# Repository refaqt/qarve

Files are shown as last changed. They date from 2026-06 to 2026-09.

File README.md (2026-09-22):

# Qarve

Open-source modular CNC milling machine — text-first, Git-friendly, [DOQS](https://github.com/refaqt/doqs) documentation system.

The repository root is the **top-level DOQS module**. Sub-assemblies will live under `modules/` when added; none exist yet.

## Quick start

1. Clone with submodules: `git clone --recurse-submodules https://github.com/refaqt/qarve.git`
2. From the repo root, agents run `bash setup-tooling.sh` so `doqs/` and `.agents/` track latest `main`. Humans on Windows may double-click `setup-tooling.bat`. Do not run those helpers from `doqs/templates/setup-tooling/`.
3. Install https://git-lfs.com/ and run `git lfs install` before pulling CAD binaries.
4. Read `docs/onboarding.md` for tooling, validation, and agent workflow.
5. Open `architecture/machine.sysml` for system requirements, or double-click `syson.bat` for the SysON control panel (Docker Desktop once; see `doqs/docs/syson.md`).

## Validation

From the repository root:

```powershell
python doqs/doqs.py check
```

This is the same command the automatic checks run on every pull request. It checks the part manifests, the licence files, the names, the links, the build records, the variants, and the FreeCAD models. It also checks that every generated file is up to date.

To write the generated files again, run:

```powershell
python doqs/doqs.py generate
```

After adding a first-level content directory, also run `python doqs/scripts/apply_licenses.py` to give it a licence file.

## Layout

| Path | Role |
| --- | --- |
| `LICENSE` | Overview mapping directories to licences |
| `LICENSES/` | Full CERN-OHL-S, GPL-3.0, and CC BY-SA texts |
| `TRADEMARKS.md` | Reserved organisation and project marks |
| `architecture/` | Top-level SysML (requirements, interfaces) |
| `cad/` | Machine assembly FreeCAD + exports |
| `modules/` | Reserved for future sub-assemblies (empty today) |
| `builds/` | Physical machine lockfiles |
| `graph/` | Generated reverse-usage graph |
| `doqs/` | Git submodule — shared tools, templates, schemas |
| `.agents/` | Git submodule — shared agent rules and skills |
| `.agents-local/`  | Qarve-only agent rules and skills |
| `firmware/` | Motion controller and related software |
| `docs/` | Narrative: log, mistakes, decisions |

## Agents

Cursor, Claude Code, and cloud agents: start at [`AGENTS.md`](AGENTS.md). Shared kit is in
[`.agents/`](.agents/); repo-specific rules and skills in [`.agents-local/`](.agents-local/).

## Licence

This repository uses different licences for different kinds of content:

- **Hardware** (`cad/`, `architecture/`, `manufacturing/`, `bom/`, `builds/`, `modules/`) —
  [CERN-OHL-S v2.0](LICENSES/CERN-OHL-S-2.0.txt)
- **Firmware & software** (`firmware/`, `software/`, `simulation/`) —
  [GPL-3.0](LICENSES/GPL-3.0.txt)
- **Media & documentation** (`docs/`, `measurement/`) —
  [CC BY-SA 4.0](LICENSES/CC-BY-SA-4.0.txt)

The Refaqt BV, BE 0804.145.539 name and logo, and the Qarve CNC Milling Machine name and logo, are
trademarks and are not covered by the above — see [TRADEMARKS.md](TRADEMARKS.md).

See [LICENSE](LICENSE) for the full overview and directory mapping.

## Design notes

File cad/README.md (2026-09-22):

# Top-level CAD

- **FreeCAD:** v1.1+ with built-in Assembly workbench.
- **Relative paths:** `Edit → Preferences → General → Document → Use relative paths when saving external links`.

## Paths

| Path | Purpose |
|---|---|
| `assemblies/machine.FCStd` | Top assembly (future; may link into `modules/*/cad/` when sub-assemblies exist) |
| `assemblies/spindle-assembly/` | Spindle stack assembly |
| `assemblies/spindle-clamp/` | Spindle clamp sub-assembly |
| `parts/spindle/` | Purchased spindle model (JGY-80) and reference images |
| `parts/spindle-clamp-base/` | Clamp base part (recess for spindle clearance) |
| `parts/spindle-clamp-jaw/` | Clamp jaw part |
| `parts/spindle-clamp-flex/` | Clamp flex part |
| `exports/` | `.step`, `.stl` committed after significant changes |

## Top-down design (spindle clamp)

Master sketches for the clamp live in `spindle-clamp.FCStd` inside a `Master sketches` group and a dedicated `Body_master` (`PartDesign::Body`). Sketches use **that Body's origin planes**, not the `Assembly` object's origin planes. Child parts (`spindle-clamp-base`, `spindle-clamp-jaw`) consume geometry via `SubShapeBinder` pointing at sketches inside `Body_master`.

This avoids a circular document dependency (assembly → part → assembly) that blocks Assembly **Insert**. See `doqs/docs/decisions/2026-06-24_freecad-master-sketches-body.md` and `doqs/docs/architecture.md` (Top-down design and master sketches).

Binary `.FCStd` / `.stl` use Git LFS (see root `.gitattributes`).

## After you save a model

Every `.FCStd` has a `.fingerprint.json` beside it. It lists the size, the
position and the volume of each object, so a change to the geometry can be read
as text in a pull request. The checks fail when a model and its measurement
disagree.

Run this from the repository root after saving, and commit the model and the
measurement together:

```powershell
python cad/fingerprint_models.py
```

The script opens each model, measures it and closes it. It never saves a
`.FCStd`: geometry changes stay manual, in the FreeCAD window. The run ends by
naming any model whose geometry moves when FreeCAD refreshes it, which means the
saved file no longer matches its own sketches and joints.

Why this repository measures models instead of rebuilding them:
[`docs/decisions/2026-09-22_fingerprints-for-hand-drawn-models.md`](../docs/decisions/2026-09-22_fingerprints-for-hand-drawn-models.md).

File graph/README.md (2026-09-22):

# Usage graph

`usage-graph.json` is **generated** by `doqs/scripts/resolve_graph.py` and committed as a snapshot of which parents and builds reference each module.

```powershell
python doqs/doqs.py generate
```

To check that the committed file is still current, without writing it:

```powershell
python doqs/scripts/resolve_graph.py --check
```

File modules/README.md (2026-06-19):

# Modules

This directory is reserved for **sub-assemblies** — each a full DOQS module with the same layout as the repository root (`bom/`, `cad/`, `architecture/`, `docs/`, `manufacturing/`, `modules/`).

**Current state:** Qarve is a single top-level module. No sub-assemblies exist yet.

When you add the first sub-module:

1. Create `modules/<name>/` with the standard module layout.
2. Register it in the root `okh.toml` via `[[hasComponent]]`.
3. Import its SysML from `architecture/machine.sysml`.
4. Pin it in `builds/<id>/build.toml`.

Later, a sub-module can be extracted to its own repository and linked back as a Git submodule at the same path — see [doqs/docs/architecture.md](../doqs/docs/architecture.md).

Interface version bridges live under `modules/adapters/` by convention.

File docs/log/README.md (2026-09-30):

# Activity log

Chronological record of work on Qarve (engineering and design). Entries follow
`YYYY-MM-DD_topic.md`, newest listed last. Every entry must include **Role(s)**.

To add an entry, see [`.agents/skills/log/SKILL.md`](../../.agents/skills/log/SKILL.md).

| Date | Topic | Role(s) | Images |
| ---- | ----- | --- | -----: |
| 2026-06-04 | [Repository bootstrap](2026-06-04_repository-bootstrap.md) | engineering |  |
| 2026-06-23 | [Spindle clamp design](2026-06-23_spindle-clamp-design.md) | engineering |  |
| 2026-06-26 | [Guide-rail adjustment simulation](2026-06-26_guide-rail-adjustment-simulation.md) | engineering |  |
| 2026-06-26 | [Z-axis CAD bootstrap](2026-06-26_z-axis-cad-bootstrap.md) | engineering |  |
| 2026-08-11 | [FEM CalculiX assembly material/mesh workflow](2026-08-11_fem-calculix-assembly-workflow.md) | engineering, simulation |  |
| 2026-08-15 | [X-axis Params and AssemblyLink pattern](2026-08-15_x-axis-params-assemblylink-pattern.md) | engineering, cad |  |
| 2026-08-28 | [Taiwanese ATC spindle supplier research](2026-08-28_taiwanese-atc-spindle-suppliers.md) | engineering |  |
| 2026-08-28 | [Agent kit and log restructure](2026-08-28_agent-kit-and-log-restructure.md) | engineering |  |
| 2026-08-31 | [Split-licence layout](2026-08-31_split-licence-layout.md) | engineering |  |
| 2026-09-01 | [Always-latest tooling submodules](2026-09-01_always-latest-tooling-submodules.md) | engineering |  |
| 2026-09-01 | [SysON session adapter](2026-09-01_syson-session-adapter.md) | engineering, software |  |
| 2026-09-22 | [Linear axis reworked around the steel strip seal](2026-09-22_linear-axis-seal-roller-clearance.md) | engineering, cad |  |
| 2026-09-22 | [The repository passes its own checks again](2026-09-22_repository-passes-its-own-checks.md) | engineering, software |  |
| 2026-09-23 | [Linear stage base redrawn as one aluminium block](2026-09-23_linear-stage-monoblock-base.md) | engineering, cad | 1 |
| 2026-09-25 | [Strip seal is thicker and bends on a larger radius](2026-09-25_strip-seal-thicker-with-larger-bend-radius.md) | engineering, cad |  |
| 2026-09-28 | [Controller comparison: grblHAL and ncSender against LinuxCNC and EtherCAT](2026-09-28_controller-comparison-grblhal-vs-linuxcnc-ethercat.md) | engineering, firmware, software |  |
| 2026-09-30 | [Idea: a printed clamp with crossed countersunk screws](2026-09-30_crossed-countersunk-screw-clamp-idea.md) | engineering, hardware | 1 |
| 2026-09-30 | [Y-axis mounted on the frame with eccentric countersunk screws](2026-09-30_y-axis-to-frame-connection.md) | engineering, hardware | 2 |

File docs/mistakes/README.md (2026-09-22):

# Mistakes log

One file per incident: `YYYY-MM-DD_short-topic.md`. Use template `doqs/templates/mistake-entry.md`.

Agents: read all recent entries (or this README’s prevention summary) at task start; append a new file after each mistake — do not use a single `mistakes.md` at repo root.

## Prevention rules (bootstrap)

- Do not edit `.FCStd` files in the agent — use FreeCAD and param CSV workflow.
- Do not hand-edit generated `bom/bom.csv` (root) or `cad/params.csv`.
- Run `python doqs/doqs.py check` before claiming manifests, builds or models are valid.
- After `apply_licenses.py`, confirm `.agents/` and `doqs/` are unmodified (tooling submodules, not machine modules).
- A check that reads a `.FCStd` must be proved on a fresh checkout. Git LFS files are stubs there unless the checkout fetches them.

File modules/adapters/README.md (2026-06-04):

# Adapter modules

Modules that translate between **interface versions** (e.g. spindle mount v1 → v2). Same layout as any other module; declare both `[[provides-interface]]` and `[[consumes-interface]]` in `okh.toml`.

Browse this folder for supported upgrade paths on deployed machines.

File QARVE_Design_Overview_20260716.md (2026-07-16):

# QARVE — Compact 5-Axis CNC Milling Machine: Design Overview

*Reference summary derived from `QARVE__Architecture_Calculations_BOM__20260716.xlsx` (preliminary design, updated 2026-07-16). This document is a navigation aid for the project: it summarizes the concept, kinematics, key calculated numbers, the major components and their suppliers, and known data-quality caveats so that questions can be answered without re-reading the full workbook. Changes versus the prior 2026-06-18 revision are noted inline (the X-axis linear-motor peak-force shortfall is now resolved; the BOM was reorganized and the machine total is lower).*

---

## 1. What QARVE is

QARVE is a **compact, table-tilting 5-axis CNC milling machine** intended to sit on roughly **half a EUR pallet**. The three linear axes (X, Y, Z) position the spindle/tool, and two rotary axes (A, C) orient the workpiece on a **trunnion (cradle) rotary table**. It is built largely from **aluminium extrusion** and uses **direct-drive linear motors** on the linear axes and **frameless torque motors** on the rotary axes.

The design is captured in a single workbook that combines a **parametric system model** (cutting physics → axis loads → motor/component sizing), a **bill of materials with architecture tree**, and a **supplier/specification comparison** that checks each chosen component against the model's requirements.

### Headline figures

| Item | Value |
| --- | --- |
| Axes | 5 — X, Y, Z (linear) + A, C (rotary) |
| Linear travels | X = 310 mm · Y ≈ 356 mm total (≈256 mm machining + 100 mm tool change) · Z = 222 mm |
| Max workpiece | Ø230 mm × 210 mm tall; ≈163 × 163 mm if square; **15 kg** max |
| Target machine footprint | ≤ 600 mm (X, ½ EUR-pallet length) × 800 mm (Y, EUR-pallet width) |
| Spindle | Jianken JGY-80/3.2R24-encoder, PMSM, **ISO20**, up to ~30,000 rpm |
| Materials targeted | Aluminium 6061, Stainless 304L, Titanium Ti-425 (roughing + finishing each) |
| Finishing stiffness target | ≤ **2 µm** deflection at ≈95 N finishing force |
| Indicative total BOM cost  | ≈ **€21,029** (Parts/Architecture roll-up, EUR). Note: this **excludes the Accessories block (A21, ≈€2,820)**, which is defined but currently detached from the machine tree — see §7–8. With accessories re-attached the effective total is ≈**€23,850**. See §8 for the one USD-quoted line and how it's handled. |

---

## 2. Kinematics & axis architecture

QARVE is a **moving-gantry / tilting-table** configuration:

- **Gantry** spans the work zone on two **80 mm support columns**; the gantry beam is ~530 mm long.
- **X axis** — the spindle carriage traverses *along* the gantry beam (310 mm travel).
- **Y axis** — motion along the machine frame (≈356 mm total travel; frame length in Y ≈760 mm).
- **Z axis** — vertical spindle motion (222 mm), counterbalanced by gas springs.
- **A axis** — the **trunnion/cradle tilt** that swings the rotary table; carries the largest rotary load (heavy, eccentric — see §4).
- **C axis** — the **rotary worktable** (circular T-slot table) seated in the cradle.

> **Naming note (updated):** In the 2026-07-16 workbook the *Groups* sheet now labels the rotary-table group **G05 as "Axis C"**, consistent with Parts/Architecture. The earlier "Axis B (G05)" discrepancy is resolved. A = tilt, C = table rotation.

All three linear axes share a common motion architecture: HIWIN profile rail + blocks, an iron-core linear motor (Saho **WJM50-3** — new selection this revision, see §4), a linear encoder for feedback, bellows covers, end stops, limit sensors, and shock dampers. Both rotary axes share: a frameless torque motor, roller bearings, bearing/motor housings, a rotor disk, and a rotary encoder.

---

## 3. Cutting capability & the system model

The "System model" sheet is the parametric heart of the workbook. For each **material × operation** it sets cutting parameters and tool geometry, then computes forces, torque, power and required dynamics. Cases modelled:

| Case | Tool (Hans Treiber) | Ø | Flutes | vc (m/min) | Spindle (rpm) | Cutting power (W) | Spindle torque (Nm) | Resultant cut force (N) |
| --- | --- | ----- | --- | --- | --- | --- | --- | --- |
| Aluminium 6061 — roughing | RG28-88RZ (N 1.2) | 10 mm | 3 | 620 | ~19,700 | ~1,491 | 0.72 | ~192 |
| Aluminium 6061 — finishing  | HP-AL3L-DLC (N 1.2) | 6 mm  | 3 | 450 | ~23,900 | ~236 | 0.094 | ~42 |
| Stainless 304L — roughing | RG26-48TZ (M 2.1) | 10 mm | 4 | 130 | ~4,140 | ~325 | 0.75 | ~201 |
| Stainless 304L — finishing  | RG26-44T (M 2.1) | 6 mm  | 4 | 120 | ~6,370 | ~115 | 0.17 | ~77 |
| Titanium Ti-425 — roughing  | RG26-48TZ (S 1.2) | 10 mm | 4 | 100 | ~3,180 | ~239 | 0.72 | ~192 |
| Titanium Ti-425 — finishing | RG26-48TZ (S 1.2) | 6 mm  | 4 | 100 | ~5,310 | ~118 | 0.21 | ~95 |

Material cutting coefficients used: aluminium Kc1.1 = 800 MPa (mc 0.25); stainless Kc1.1 = 2150 MPa (mc 0.20); titanium Kc1.1 = 2110 MPa (mc 0.22). Target metal-removal rate (MRR) for aluminium roughing is 50 cm³/min.

The model uses a chip-thinning / energy-weighted Kc approach (radial chip-thinning factor, average Kc at max chip thickness) to derive **tangential, feed, transverse and axial forces**, and from those the **spindle torque/power** and the **per-axis acceleration forces**. The governing worst case for sizing the linear axes and rotary process force is **≈201 N resultant cutting force** (stainless/titanium roughing); the **finishing** worst case (~95 N, titanium) drives the **2 µm stiffness** requirement.

> Two trailing sheets — *"Oblique cutting constants (not used)"* and *"Cutting force model (replaced w…)"* — are **deprecated**. The oblique-cutting table holds representative orthogonal constants that the notes say were *not* used; the old cutting-force model sheet is full of `#REF!` errors and has been superseded by the per-case calculations in "System model." Treat both as historical, not authoritative.

---

## 4. Motor & drive sizing (calculated requirements → selected hardware)

### Linear axes (X / Y / Z)

- Peak per-axis acceleration ≈ 19.1 m/s² (feed) / 13.9 m/s² (rapids); rapid speed 5,000 mm/min.
- Continuous motor force required ≈ **201 N**; peak force required ≈ **418 N (Z) / 479 N (Y) / 565 N (X)** — X remains the worst case at **564.8 N**.
- **Selected (changed this revision):** Saho **WJM50-3** forcer (200 mm, force constant 52.2 N/A, 240 N continuous, **750 N peak**, 4.6 A cont., 600 V, 139.7 W thermal @100 °C) on Saho **DJM050** stators (DJM050-L80 + DJM050-L200). Forcer unit cost ≈€101 (vs ≈€172 for the old WKM030-2), which is the main reason the X/Y/Z assembly costs dropped (§7).
- ✅ **Open issue RESOLVED:** with the WJM50-3's **750 N peak** rating, the X-axis peak-force requirement (564.8 N) now passes with margin. **All linear-motor spec lines are TRUE** in this revision. (The previously selected Saho WKM030-2 — 532 N peak, 106 W thermal, 4.5 A — failed on peak force, continuous current, force constant, resistance and thermal power, and is now the rejected alternative.)
- ⚠ Note the trade: WJM50-3 continuous thermal dissipation is **139.7 W** per forcer (vs 106 W for the old part), raising per-axis and total machine heat (see below) — worth watching for natural-cooling margin, though continuous force (201 N) sits well under the 240 N continuous rating.

### Rotary axes (A / C)

- A-axis (trunnion) continuous torque required ≈ **27.7 Nm** (dominated by the eccentric centre-of-gravity of the cradle, ~31.4 Nm static term, plus eccentric workpiece up to ~4.6 Nm and process torque).
- C-axis (table) continuous torque required ≈ **23.1 Nm**.
- **Selected:** **Mosrac U16060** frameless torque motor (torque constant 1.6 Nm/A, 32 Nm continuous, 45 A peak, 48 V DC, 0.96 Nm cogging, 0.24 Ω) — unchanged; all spec lines pass. Unit cost rolled in ≈€520 (USD-quoted supplier line, see §8). Resistive heaters appear on the A-axis (thermal conditioning).
- Alternatives evaluated but rejected: Mosrac U20060, and Seninter/3Phis DDM140050-PM and DDM140070-PM (the DDM140050-PM fails several lines — torque constant 9.9 vs 1.6 Nm/A, continuous/instant current, and 380 V vs 48 V DC-voltage mismatch).

### Drives & power

- **Servo drives:** Nanotec **N5-2-1** (one per motion axis; 6 listed in the BOM, ≈€363 each rolled).
- **Spindle drive:** **Cumark ES850S-02-4K0G-encoder** VFD (≈€327), matched to the encoder spindle for closed-loop / constant-torque-at-low-speed operation.
- **Power:** 48 V / 500 W supply + 12 V supply; per-motor fuses, overcurrent protection, differential breaker; a **mini-PC** acts as the controller.
- Estimated **max continuous machine heat ≈ 171 W** (up from ≈159 W, driven by the higher-dissipation linear forcers); A-axis still dominates at ~72 W (C ~50 W, X ~49 W, Y ~49 W, Z ~27 W).

---

## 5. Spindle

- **Selected (model designation updated):** Jianken **JGY-80/3.2R24-encoder** — a permanent-magnet synchronous-motor spindle, 80 mm body, **ISO20** tool interface, ~10 kg (12 kg with mount), 8.6 A. This revision selects the **encoder-equipped** variant (closed-loop, constant torque at low speed), rolled in at **≈€1,378** (the plain JGY-80/3.2R24 without encoder was ≈€1,178). The earlier "JGY-80/3.7R24" designation is now a listed alternative with no confirmed price.
- Requirement checks all pass: needs ≥3,200 W rated (model needs ~1,657 W), ≥1.32 Nm (needs 0.75 Nm), reach the ~23,900 rpm finishing speed (spindle goes to ~30,000 rpm), runout ≤5 µm (spindle 3 µm), ISO20 match, 8.6 A.
- Paired VFD: **Cumark ES850S-02-4K0G-encoder** (≈€327).
- Spindle rigidity at the tool tip is taken as ~47 N/µm.
- **Alternatives evaluated:** HSD ES330 (€3,500), Teknomotor ATC71-A-ISO30 (€3,500), Hiteco QE-1F (€4,045) / QD-1F (€3,495), and the cheaper Jianken JGL-80/2.2R30. The encoder JGY unit was chosen as the best cost/performance fit.

---

## 6. Structure, precision & enclosure

- **Frame & base:** aluminium extrusion — 80×80 profiles (large), 40 mm (small). The base uses ~17× 80×80×1000 extrusions plus support feet, chip bin, doors and covers; the frame uses 80×80×600 extrusions plus laser-cut side/front/back/inner plates and rubber feet.
- **Gantry beam:** aluminium, area moment of inertia 4,202,400 mm⁴ (from the Misumi catalog), E = 69,000 MPa → ~**374 N/µm** stiffness for a centre point load (clamped-clamped, rails not included).
- **Precision target:** ≤ **2 µm** total machine deflection during finishing at the ~95 N finishing force; tool-tip spindle rigidity ~47 N/µm.
- **Enclosure/housing:** 15 mm enclosure walls with 5 mm clearance to the machine; housing side panels, extrusion sub-frame and a door.

---

## 7. Bill of materials & sub-systems

The **Parts** sheet defines the assemblies (`A01…A21`) and parts (`P01…P82`); **Architecture** is the parent→child tree that rolls quantities and costs up to the top-level assembly **QARVE (A01)**.

**BOM reorganization this revision (read before quoting the total):** the top-level tree was restructured. The **tool setter (P75)**, **wireless touch probe (P76)** and a new **Lighting (P82)** item were promoted to *direct* children of QARVE (A01), and **Control panel (A12)** is now a direct A01 child. Crucially, the **Accessories assembly (A21)** — 12× ISO20 tool holders (€1,800), a **vise set** (€300) and a 12-piece **tool set** (€720), €2,820 total — is **defined but no longer attached to A01**, so it is **not rolled into the machine total**. This is most likely an unintended orphan from the restructure (the probe/setter were moved out of A21 to A01 but the remaining accessories were left detached); flag it before treating €21,029 as the all-in cost.

Direct children of QARVE (A01) and their rolled costs (EUR, as recorded in the workbook):

| Assembly / part | Rolled cost (€) | Notes |
| --- | --- | --- |
| X-axis (A02) | 1,920 | linear motor (WJM50-3) + HIWIN guides + encoder + extrusion |
| Y-axis (A03) | 1,654 | two forcers (longer travel) |
| Z-axis (A04) | 1,020 | + gas-spring counterbalance |
| A-axis (A05) | 1,990 | trunnion: torque motor, bearings, cradle plates, heaters |
| C-axis (A06) | 1,960 | rotary T-slot table, torque motor, bearings |
| Spindle assembly (A07) | 1,778 | spindle + bracket + Cumark VFD |
| Frame (A08) | 1,980 | extrusion + plates |
| Base (A09) | 2,260 | extrusion, doors, chip bin |
| Housing (A10) | 380 | panels + door |
| Electronic system (A11) | 3,477 | drives, PSUs, protection, mini-PC, cabinet |
| Control panel (A12) | 700 | now a direct A01 child |
| Tool coolant system (A13) | 350 | **MQL** (minimum-quantity lubrication) |
| Pneumatic system (A14) | 600 | compressor, filter, valve, components |
| Tool cabinet (A15) | 760 | manual tool storage (tool array holders) |
| Tool setter (P75) | 50 | promoted to direct A01 child |
| Wireless touch probe (P76) | 150 | promoted to direct A01 child |
| Lighting (P82) | 0 | new line, placeholder cost |
| **QARVE total (A01)** | **≈ 21,029** | top-level roll-up (**excludes** detached Accessories A21) |
| *Accessories (A21) — detached* | *2,820* | *vises, tool set + 12 holders; not in the A01 total this revision* |
| *Effective total with A21 re-attached* | *≈ 23,849* | *if the orphan is intended to be included* |

**Accessories & metrology:** a **wireless touch probe** and a **tool setter** (now direct machine sub-assemblies); a **vise set** (low-profile vise + dedicated 5-axis vise); a **tool set** of 12 tools on 12 ISO20 tool holders stored in the tool cabinet (no automatic tool changer — tool change uses the 100 mm Y allowance and the cabinet). The vise set, tool set and tool holders sit under the currently-detached A21 assembly.

### Key suppliers (selected)

- **Sorotec** (DE) — tool holder (ISEL SK20), HIWIN linear guide rails (HGR20) and blocks (HGH20CA).
- **Saho** — linear motor forcers and stators (**WJM50-3** forcer + **DJM050-L80 / DJM050-L200** stators; changed from WKM030-2 / DKM030 this revision).
- **Sino** — linear encoders (KA-500 series).
- **Nanotec** — N5-2-1 servo drives.
- **Mosrac** — U16060 frameless torque motors.
- **Jianken** — **JGY-80/3.2R24-encoder** spindle, with a **Cumark ES850S** VFD.
- **Hans Treiber / fraeser-shop** — solid-carbide end mills (the tools in §3).

---

## 8. Data-quality caveats (read before quoting numbers)

1. **Cost reconciliation error (persists).** The *Groups* sheet still flags **"ERROR: double-counted — an assembly…"**. The sum of the per-group costs (now ≈**13,426**, down from ≈14,452) does **not** equal the top-level QARVE cost (≈21,029); the difference is partly un-grouped systems (frame, base, housing, electronics, coolant, pneumatics, tool cabinet, control panel, probe/setter) and partly a flagged double-count (servo drives are children of the Electronic system yet also tagged to axis groups). The reconciliation's "top-level (root) cost" cell also reads 0 because its `SUMIFS` matches `type="assembly"` (lower-case) while Parts stores `"Assembly"` — a case-mismatch that leaves the check permanently in the error state. **Use the Parts/Architecture roll-up (≈21,029) as the machine total**, and treat group subtotals with caution.
2. **Detached Accessories block (new this revision).** Assembly **A21 (Accessories, €2,820)** is defined but **not a child of A01**, so it is excluded from the €21,029 roll-up (see §7). The tool setter and touch probe were promoted to direct A01 children, but the vise set, tool set and 12 tool holders were left orphaned — most likely unintended. If accessories belong in the machine cost, the effective total is ≈**€23,849**. Decide and re-attach (or confirm the exclusion is deliberate) before quoting a single "machine cost".
3. **Currency — confirmed EUR.** All BOM/unit costs in the workbook are EUR. One supplier line is quoted in USD — the Mosrac U16060 torque motor (Suppliers note: *"2pcs: 520USD/pcs, 20pcs:480USD/pcs, …"*). This revision converts it **live** via `GOOGLEFINANCE("CURRENCY:USDEUR")` (cached ≈0.87 EUR/USD, giving ≈€478.6 at the 2-piece break, plus a small handling term); the unit cost actually rolled into the total (**≈€520.4**) comes from a power-law curve fit across the quantity breaks evaluated at the machine quantity. Either way the figure is in EUR terms, so the ≈€21,029 total is not understated by an unconverted USD amount. No other USD lines exist in the workbook.
4. **X-axis peak force — RESOLVED.** The linear motor was changed from Saho WKM030-2 (532 N peak, which failed the 564.8 N requirement) to Saho **WJM50-3 (750 N peak)**; all linear-motor spec lines now pass (§4). This caveat from the prior revision is closed. Watch item: WJM50-3 thermal dissipation is higher (139.7 W vs 106 W per forcer), nudging total machine heat to ≈171 W.
5. **Deprecated sheets.** "Oblique cutting constants (not used)" and "Cutting force model (replaced w…)" are historical; the latter still contains thousands of `#REF!` cells. Don't rely on them.
6. **Preliminary status.** This is a *preliminary* design updated 2026-07-16; numbers are model outputs and supplier quotes, not as-built measurements.

---

## 9. Workbook map (where to find what)

| Sheet | Contents |
| --- | --- |
| **System model** | Parametric calculations: per-material cutting cases, axis loads, motor sizing, geometry/travel, thermal. The single source of truth for requirements. |
| **Parts** | Flat list of every assembly/part with type, supplier flag, unit & rolled cost, quantity. |
| **Architecture** | Parent→child BOM tree; rolls quantities/costs up to QARVE (A01); assigns axis groups. |
| **Groups** | Per-group (axis) cost subtotals + the cost reconciliation check (still flagging an error; group sum ≈13,426). G05 now labelled "Axis C". |
| **Suppliers** | Candidate suppliers per part with model numbers, links, price breaks, and the "chosen supplier" flag. |
| **Specifications** | Each candidate component's specs checked against the model's requirement (OK? column). |
| **Tools** | End-mill catalog (brand, geometry, cutting speed, feed-per-tooth, ae) used by the cutting cases. |
| **Material constants** | Kc1.1 / mc lookup by material and material group. |
| **Oblique cutting constants** | *Deprecated / not used.* |
| **Cutting force model** | *Deprecated / replaced;* contains `#REF!` errors. |

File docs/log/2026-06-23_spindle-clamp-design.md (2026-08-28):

# 2026-06-23 — Spindle clamp design

**Role(s):** engineering

## Goal

Design a spindle clamp sub-assembly (base + jaw) around the JGY-80 spindle model, using top-down master sketches in FreeCAD.

## Work Done

- Iterated spindle clamp layout in `cad/assemblies/spindle-clamp/` (design workspace was later removed after width reduction).
- Added recess in `spindle-clamp-base` for spindle clearance.
- Fixed `spindle-clamp-base` Binder link error (part failed to appear in Assembly Insert).
- Adopted DOQS pattern: master sketches in `Body_master` with Body origin planes (not Assembly origin planes) to break assembly ↔ part document cycle.
- Reduced clamp width; accepted increased height as a trade-off (harder to manufacture on Qarve).
- Explored `spindle-clamp-flex` as an alternative and rejected it: either clamping force must be too high (thick collar) or rigidity is questionable (thin collar).

## Decisions Made

- Top-down driving geometry stays in the assembly file's `Body_master`; parts consume via `SubShapeBinder`.
- Purchased spindle remains reference geometry in `cad/parts/spindle/spindle.FCStd`.
- Width-reduced clamp geometry is preferred over the flex variant.

## Open Questions

- [ ] Torque specs and fastener sizes for clamp screws
- [ ] Export `.step` / `.stl` for manufactured parts after geometry freeze

## Next Steps

- [ ] Integrate spindle clamp into `spindle-assembly` stack
- [ ] Add BOM entries when part list is finalized

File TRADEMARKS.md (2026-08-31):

# Trademarks

"Refaqt BV, BE 0804.145.539" and the Refaqt BV, BE 0804.145.539 logo, and "Qarve CNC Milling Machine" and
the Qarve CNC Milling Machine logo, are trademarks of Refaqt BV, BE 0804.145.539.

These marks are **not** covered by the CERN-OHL-S v2.0, GPL-3.0, or CC BY-SA
4.0 licences that apply to the hardware designs, firmware/software, and
media/documentation in this repository respectively (see [`LICENSE`](LICENSE)).
You are free to use, modify, and redistribute the technical content of this
repository under those licences, but that permission does not extend to the
Refaqt BV, BE 0804.145.539 or Qarve CNC Milling Machine names or logos.

You may not:

- Use the Refaqt BV, BE 0804.145.539 or Qarve CNC Milling Machine names or logos on a modified
  or derivative design, product, or piece of software in a way that implies
  it is the original project or is endorsed by Refaqt BV, BE 0804.145.539.
- Use the Refaqt BV, BE 0804.145.539 or Qarve CNC Milling Machine names or logos in the name or
  branding of a fork, derivative, or unrelated product.
- Use the Refaqt BV, BE 0804.145.539 or Qarve CNC Milling Machine names or logos in any way
  likely to cause confusion about the origin or affiliation of a product.

Referring to this project by name (e.g. "based on Qarve CNC Milling Machine",
"compatible with Qarve CNC Milling Machine") for accurate, non-confusing description
is fine. For any other use of the marks, contact Refaqt BV, BE 0804.145.539 for
permission.

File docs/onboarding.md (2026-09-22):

# Onboarding — Qarve (DOQS)

## What this repository is

A **modular open-hardware** CNC machine project using the Documentation System (DOQS): text-first files, identical module layout at every depth, SysML for requirements, FreeCAD for geometry, OKH manifests for publishing.

Qarve is currently a **single top-level module**. Sub-assemblies will be added under `modules/` later.

## Prerequisites

- Git and [Git LFS](https://git-lfs.com/)
- Python 3.11+ (stdlib `tomllib` for validators)
- FreeCAD 1.1+ (Assembly workbench) for CAD work
- [Docker Desktop](https://docs.docker.com/desktop/setup/install/windows-install/) once, for graphical SysML in SysON (optional until you edit models in the browser)

## Setup

```powershell
git clone --recurse-submodules https://github.com/refaqt/qarve.git
cd qarve
git lfs install
bash setup-tooling.sh
python -m venv .venv
.venv\Scripts\Activate.ps1
```

### DOQS tools path

Validators and templates live at **`qarve/doqs/`** (Git submodule). Run all `python doqs/scripts/...` commands from the **qarve repository root**.

A separate clone of [github.com/refaqt/doqs](https://github.com/refaqt/doqs) elsewhere on disk (e.g. `../doqs`) does **not** satisfy these paths. Use `bash setup-tooling.sh` after clone (agents, any OS), or create a junction/symlink from `qarve/doqs` to your existing clone if you prefer that workflow. Humans on Windows may double-click `setup-tooling.bat`.

## Validation (run from repo root)

```powershell
python doqs/doqs.py check
```

This is the same command the automatic checks run on every pull request. It checks the part manifests, the licence files, the names, the links, the build records, the variants, and the FreeCAD models. It also checks that every generated file is up to date.

When a check says a generated file is stale, write them all again and read the result before you commit:

```powershell
python doqs/doqs.py generate
```

That one command writes the parameter table, the resolved instance files, the licence files, the top-level bill of materials, and the usage graph.

After adding a first-level content directory, give it a licence file. Never point this at `doqs/` or `.agents/`, which are tooling and carry their own licences:

```powershell
python doqs/scripts/apply_licenses.py
```

## After you save a FreeCAD model

Every `.FCStd` has a small measurement file beside it, so a change to the geometry can be read as text in a pull request. The checks fail when a model and its measurement disagree. Run this after saving, and commit the model and the measurement together:

```powershell
python cad/fingerprint_models.py
```

It never saves a `.FCStd`. Geometry changes stay manual, in the FreeCAD window. More in [cad/README.md](../cad/README.md).

## Graphical SysML (SysON)

Requirements live in `architecture/*.sysml`. To edit them in Eclipse SysON:

1. Install Docker Desktop once (see [doqs/docs/syson.md](../doqs/docs/syson.md)).
2. Double-click `syson.bat` at this repository root (or run `bash syson.sh`).
3. In the control panel, click **Open**, edit in SysON, then click **Save**.
4. Review `git diff` before committing.

Do not use SysON’s homepage **Download** (JSON zip). **Save** writes textual `.sysml` back into `architecture/`.

Agents: `python doqs/scripts/syson.py ui` (do not run `syson.bat`).

## Where to read

| Path | Content |
|---|---|
| `docs/architecture.md` | Short overview — full spec in `doqs/docs/architecture.md` |
| `LICENSE` / `LICENSES/` / `TRADEMARKS.md` | Split-licence overview, full texts, reserved marks |
| `doqs/docs/readiness-levels.md` | OTRL / ODRL definitions |
| `architecture/*.sysml` | Authoritative requirements and interfaces |
| `modules/*/architecture/` | Sub-module SysML (when `modules/` is populated) |
| `docs/log/` | Activity log (dated entries) |
| `docs/mistakes/` | Incident log (dated files) |
| `docs/decisions/` | ADRs (dated files) |
| `docs/skills.md` | Pointer to `.agents-local/skills/patterns/SKILL.md` |
| `AGENTS.md` | Agent entry point (Cursor, Claude Code, cloud agents) |
| `.agents/` | Git submodule — shared refaqt-agents rules and skills |
| `.agents-local/` | Qarve-only agent rules and skills |
| `.cursor/rules/` | Cursor adapters + DOQS-scoped rules |
| `.claude/skills/` | Claude Code skill symlinks |
| `doqs/templates/` | Entry templates |

## Design session checklist

See root `CONTRIBUTING.md` and the DOQS architecture document in `doqs/docs/architecture.md`.

## Cursor / Claude / agents

- Entry point: [`AGENTS.md`](../AGENTS.md)
- Shared kit: [`.agents/`](../.agents/) ([refaqt-agents](https://github.com/refaqt/refaqt-agents))
- Repo-specific rules: [`.agents-local/rules/`](../.agents-local/rules/)
- Repo-specific skills: [`.agents-local/skills/`](../.agents-local/skills/)
- Cursor adapters: [`.cursor/rules/`](../.cursor/rules/)

Use the shared [`log`](../.agents/skills/log/SKILL.md) skill when a session is worth recording.

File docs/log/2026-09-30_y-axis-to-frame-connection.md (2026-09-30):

# 2026-09-30 — Y-axis mounted on the frame with eccentric countersunk screws

**Role(s):** engineering, hardware

## What happened

Two hand sketches show a way to fix the Y-axis to the machine frame. The Y-axis
base (the aluminium monoblock) sits on top of an 80 × 80 mm aluminium
T-slot profile. Screws with an eccentric countersunk head hold it down and let
it be adjusted. No CAD model was made yet.

This follows the [printed clamp with crossed countersunk screws](2026-09-30_crossed-countersunk-screw-clamp-idea.md),
logged the same day. That idea was judged not stiff enough. Here the eccentric
countersunk screws go straight through the monoblock into the frame profile.

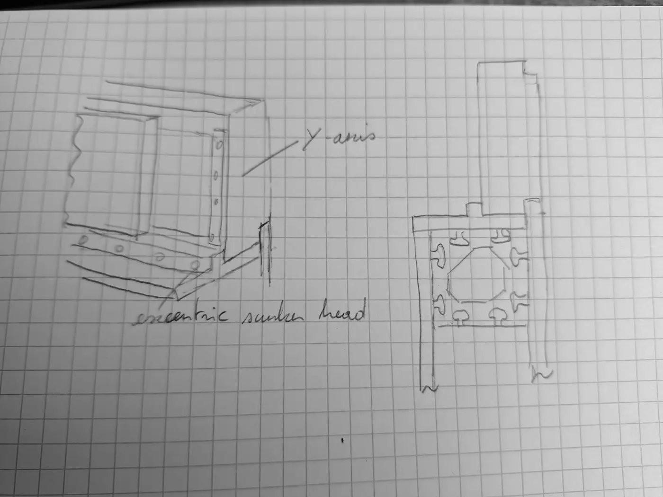
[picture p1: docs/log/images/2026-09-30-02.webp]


Sketch 1: the Y-axis on the frame profile (left), and a cross-section through
the joint (right).

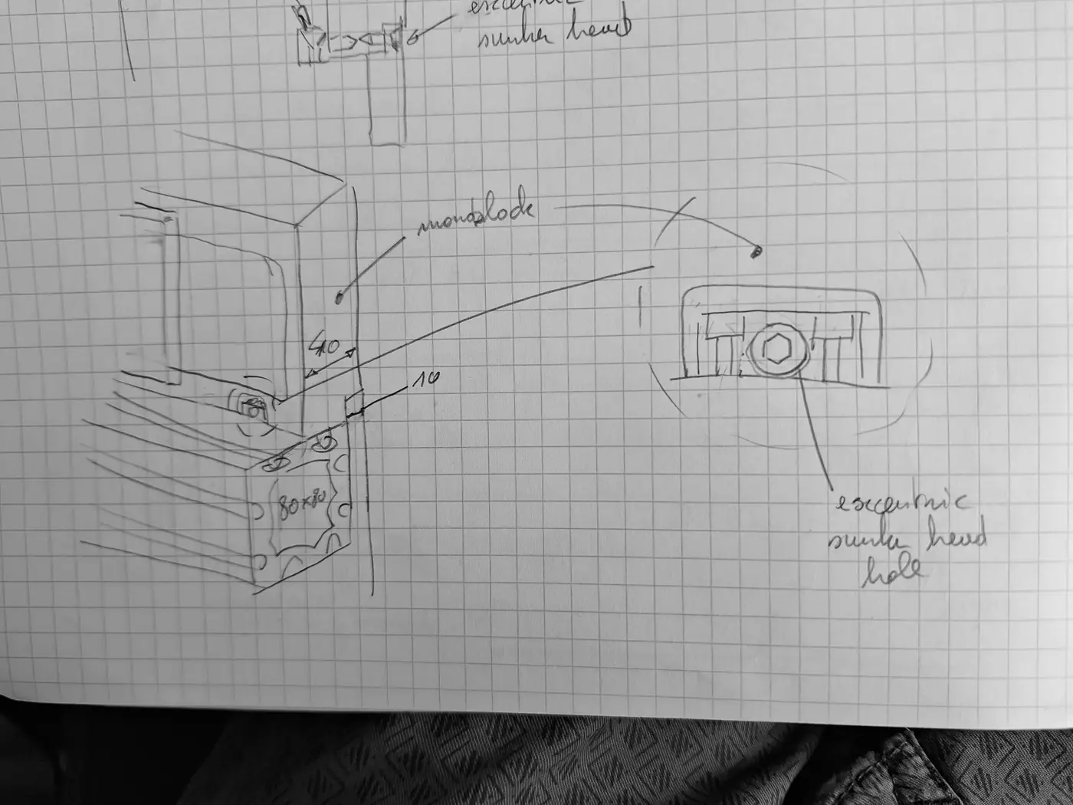
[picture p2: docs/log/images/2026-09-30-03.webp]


Sketch 2: the same corner with dimensions, and a detail of the eccentric
countersunk head hole.

### The idea as sketched

- The frame member is an 80 × 80 mm T-slot profile. The Y-axis monoblock sits
  on its top face.
- A row of screws goes down through the monoblock into the T-slots of the
  profile. Each screw has an eccentric countersunk head, set in a matching
  countersunk hole.
- Turning an eccentric head moves the monoblock sideways a little before the
  screw is tightened. This gives a fine position adjustment, for example to
  make the two Y-axes parallel.
- The cross-section shows a small key on the frame side that fits into a step
  in the monoblock, and a lip on the outer side that hangs down along the
  profile. Both locate the axis on the frame.
- Dimensions written on the sketch: **10 mm** for the lip, and **10 mm**
  between the edge of the monoblock and the screw line (read as 10 mm, could
  also be 40 mm).

## Open Questions

- Is the second dimension 10 mm or 40 mm?
- Is the lip part of the monoblock, or a separate plate between the monoblock
  and the profile?
- Which eccentric countersunk screw or bushing (size, eccentricity, supplier)?
  How much adjustment is needed?
- Does the eccentric adjustment also need a lock, so the axis does not move
  under cutting load?

## Next Steps

- [ ] Confirm the dimensions and the lip design.
- [ ] Choose the eccentric countersunk screw and find a supplier.
- [ ] Model the joint in `cad/architecture/machine.FCStd`, and add the 80 × 80
      profile and the screws to the parts list.
- [ ] If this becomes the chosen joint, record it in `docs/decisions/`.

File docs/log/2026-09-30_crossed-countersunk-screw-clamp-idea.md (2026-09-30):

# 2026-09-30 — Idea: a printed clamp with crossed countersunk screws

**Role(s):** engineering, hardware

## What happened

We looked at a way to fix the Y-axis to the frame without screw holes in the
blocks. The idea works in principle, but it is not good enough for the Y-axis
mount. The joint would slowly lose its clamping force, and a printed part is too
flexible in a milling machine.

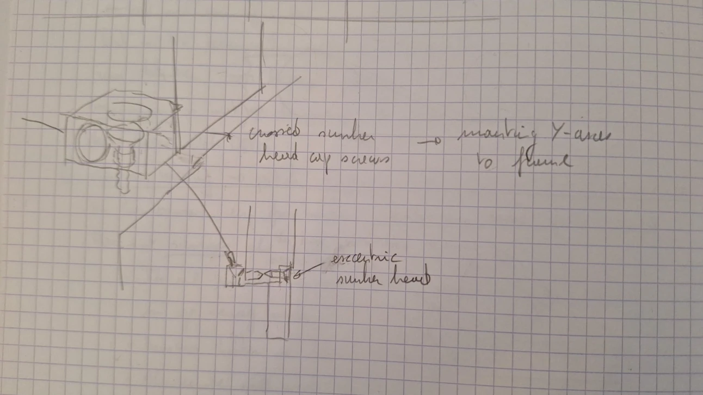
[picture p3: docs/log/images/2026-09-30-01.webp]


Hand sketch of the idea. A 3D printed holder guides two crossed countersunk
screws ("crossed sunken head cap screws → mounting Y-axis to frame"). One screw
goes into each block. The second screw has an off-centre countersink seat
("eccentric sunken head"). When you tighten it, it pulls the block down.

### Why the idea can work

- An off-centre countersink seat is a known clamping trick for fixtures. The
  cone of the screw head pushes sideways as it sits down. This turns the turn of
  the screw into a pull between the two parts.
- Two screws at opposite angles hold better against pulling out than one
  straight screw.

### Why it will come loose on Qarve

1. **Plastic carries the clamping force.** All of the force goes through the
   printed holder. Plastic slowly gives way under a constant load (creep). PLA
   does this more than PETG. The screw head sinks a little into its cone seat.
   A few tenths of a millimetre is enough to lose most of the clamping force.
   The cone also pushes outward, so the seat can split along the print layers.
2. **The off-centre seat has very little travel.** It pulls only while the cone
   sits fully on the offset. When the plastic gives way, the pull is lost. If
   you tighten again, the head only sinks deeper.
3. **Vibration.** The Y-axis linear motors (Saho WJM50-3) change direction with
   high acceleration. Each change loads the joint again. A joint that has lost
   some clamping force soon works itself loose.
4. **Stiffness.** Even when it is tight, the printed holder acts like a spring
   between the axis and the frame. This costs stiffness, accuracy and surface
   finish.
5. **Holes are still needed.** The frame is aluminium extrusion. A screw cannot
   hold in bare aluminium without a tapped hole or a nut.

## Decisions

- Do not use a printed crossed-screw clamp to carry the Y-axis load.

## Open Questions

- What is the second block exactly: the linear stage monoblock base or a motor
  housing? Which faces can a tool reach?

## Next Steps

- [ ] Fix the Y-axis base to the 80×80 and 40 mm extrusions with T-slot nuts
      (drop-in or hammer-head, M8). This needs no drilling in the frame.
- [ ] If new holes are needed, use the printed holder only as a drilling jig
      (a guide for the drill and tap). Then remove it and bolt metal to metal.
- [ ] Only for a test model, if a printed clamp must carry load: print in PETG,
      ASA or PC. Use 100% fill and at least 4 mm of wall around each seat. Put a
      metal countersunk washer in each seat. Add disc spring washers (Belleville
      washers) and medium thread-locking glue. Tighten again after 24 hours.

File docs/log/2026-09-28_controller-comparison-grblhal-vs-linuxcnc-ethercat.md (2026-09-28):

# 2026-09-28 — Controller comparison: grblHAL and ncSender against LinuxCNC and EtherCAT

**Role(s):** engineering, firmware, software

## What happened

We compared the controller that Richner Precision uses with the controller we plan for Qarve.
The result: the Richner setup is simpler and cheaper, but it does not fit a 5-axis machine with
linear motors and linear encoders. LinuxCNC with EtherCAT stays our plan.

Richner Precision is a Swiss maker of CNC mills, routers, and lathes. Their RUIX router runs
**grblHAL** on a 32-bit controller board, with **ncSender** as the operator program.

- **grblHAL** is firmware on a small microcontroller board. The board reads the G-code, plans the
  moves, and sends step and direction pulses to the motor drives. It does all the timing work
  itself, so the PC does not need to be fast or real-time.
- **ncSender** is a "G-code sender". It runs on a desktop or in a browser. It sends the program to
  the board over USB or Ethernet and shows a 3D preview, jogging, probing, and tool management. It
  does not control motion. Its project page says it was only tested on one board (Sienci SLEB-EXT).

Our plan is different. **LinuxCNC** runs on the mini-PC with a real-time Linux kernel and does
the path planning and machine geometry. **EtherCAT** is an industrial network. Every
millisecond, the PC sends a target position to each drive and reads back the real position and
the drive status. The drives close the control loops locally.

| Topic | grblHAL + ncSender (Richner) | LinuxCNC + EtherCAT (Qarve plan) |
| --- | --- | --- |
| Where the timing work runs | Microcontroller board | Real-time Linux on the mini-PC |
| Link to the drives | Step and direction pulses, one way only | Digital network, both ways |
| Position feedback to the controller | None. The controller assumes every step happened | Real position every cycle, so it detects position errors |
| Linear motors with linear encoders | Only if the drive closes the loop on its own; the controller never sees the encoder | Good fit: the drive and the controller both see the encoder |
| 5-axis trunnion (A tilt, C table) | Rotary axes move, but no tool-tip control (RTCP). The CAM program must calculate everything for one fixed setup | Built-in trunnion geometry with tool-tip control |
| Tool changer, spindle, extra inputs and outputs | Plugins exist; a full tool changer needs custom work | Configured in LinuxCNC; the spindle drive and I/O can share the EtherCAT network |
| Hardware cost | Low: one board (about €100–300) and any PC | Mini-PC with good real-time behaviour, EtherCAT drives, EtherCAT I/O modules |
| Setup work | Low: flash the board and set parameters | High: real-time kernel, EtherCAT configuration, drive tuning |
| Operator screen | Clean and simple out of the box | Needs work to reach the same quality |

The board price is an estimate and must be checked before we use it in a quote.

## Decisions

- Keep LinuxCNC with EtherCAT as the planned controller. The reasons are the 5-axis trunnion
  (we need tool-tip control) and the linear motors on X, Y, and Z (the controller must see real
  positions to stop the machine after a crash or a lost position).
- Use ncSender as a model for our operator screen. Its one-screen workflow is its strongest point.

This is not yet a formal decision record. The design overview only says "mini-PC" for the
controller.

## Open Questions

- Is the Nanotec N5-2-1 in the bill of materials the EtherCAT version? The N5 family also comes
  with other network interfaces.
- Which mini-PC has a low and stable real-time delay, and a separate network port for EtherCAT?
- Which operator screen do we start from (for example Probe Basic or a custom QtVCP screen)?

## Next Steps

- Write a decision record in `docs/decisions/` for the controller choice.
- Confirm the N5-2-1 order code with Nanotec.
- Measure the real-time delay on candidate mini-PCs before we buy one.

## Sources

- [Richner-Precision homepage](https://richner-precision.ch/)
- [Richner RUIX-Router](https://richner-precision.ch/RUIX-Router/)
- [ncSender website](https://ncsender.xyz/)
- [ncSender on GitHub](https://github.com/siganberg/ncSender)
- [QARVE design overview](../../QARVE_Design_Overview_20260716.md) (drives and power section)

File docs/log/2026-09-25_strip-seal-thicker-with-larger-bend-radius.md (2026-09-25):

# 2026-09-25 — Strip seal is thicker and bends on a larger radius

**Role(s):** engineering, cad

## What happened

Manual work in `cad/architecture/machine.FCStd`, body `Linear axis`, sketch `Sketch008`.

- The steel strip seal is now 0.25 mm thick instead of 0.1 mm.
- The strip no longer wraps tightly around the four rollers. Before, it bent around each
  roller at a radius of about 5 mm. Now it follows two S-curves, one on each side, with a
  bend radius of about 32 mm (32.13 mm on the inner face, 32.38 mm on the outer face).
- The flat top run is unchanged: from 47.7 mm to 170.7 mm, at 50 mm height.
- The four rollers keep their size (10 mm across) and their position.

Nothing else in the model changed. The model fingerprint was written again.

## A rough check on bending stress

Bending stress in the strip is about E × t / (2 × R), with E = 200 GPa for steel.

| | Thickness | Bend radius | Bending stress |
| --- | --- | --- | --- |
| Before | 0.1 mm | about 5 mm | about 2000 MPa |
| Now | 0.25 mm | about 32 mm | about 780 MPa |

The larger radius more than makes up for the thicker strip. The stress is less than half of
what it was. It may still be above the fatigue limit of spring steel, so it needs a proper check.

## Next Steps

- [ ] Check 780 MPa against the fatigue limit of the chosen strip material, for the planned
      number of cycles.
- [ ] Check that the S-curves still fit inside the profile with the 0.25 mm strip.

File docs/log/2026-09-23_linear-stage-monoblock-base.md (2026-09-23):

# 2026-09-23 — Linear stage base redrawn as one aluminium block

**Role(s):** engineering, cad

## What happened

The base of the linear axis is now drawn as one solid aluminium block (a
monoblock). The base is 3.5 mm lower than before. The steel strip seal and its
rollers moved with it. The work was done by hand in `cad/architecture/machine.FCStd`, body `Linear axis`.

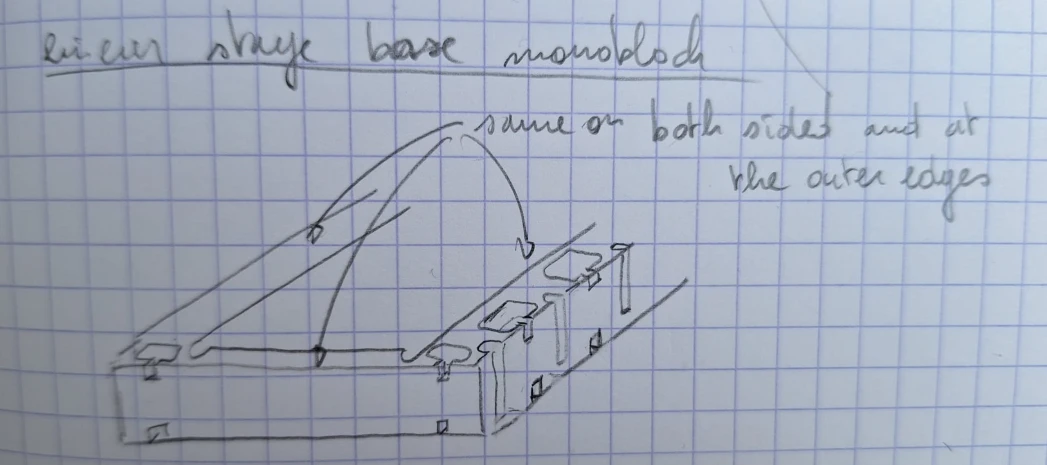
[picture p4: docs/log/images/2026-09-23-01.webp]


Hand sketch of the monoblock base. The features are "same on both sides and at
the outer edges".

### Base cross-section

- The base is now 40 mm high instead of 43.5 mm. It stays 210 mm wide.
- The inner walls stay at 23 mm and 187 mm. They now stop at 39.2 mm high,
  instead of 42.65 mm.
- The lips that hold the seal ends were redrawn with a smaller step.
- The steel strip seal is now 172 mm long instead of 170.5 mm. It lies at
  39.8 mm high and stays 0.1 mm thick.
- New: a reference line across the top at 50 mm high, from 11 mm to 199 mm.
- New: a slot 5 mm deep in the right outer face, between 5 mm and 20 mm high.
- New: the cable exit of the Saho/Maxwell linear motor mover, 6.8 mm across.
  It sits at 144.6 mm from the left face and 32.55 mm high.
- The plate and the chamfered block on the left inner wall did not change.

### Seal rollers

- The two inner rollers are now 10 mm across, instead of 9.8 mm.
- They moved 13 mm further out each. Their centres are now at 47.7 mm and
  170.7 mm, instead of 60.7 mm and 157.7 mm.
- They moved 5.1 mm down, to 45 mm high. The highest point of the strip path is
  now 50 mm, instead of 55 mm. The strip lifts less over the carriage.
- The two outer rollers did not change.

The machine footprint, enclosure, boundary, top view and both rotary-axis bodies
were not touched.

## Open Questions

- The sketch shows slots on both outer faces. The model has the outer slot on
  the right side only. Confirm that it should be mirrored to the left side.

## Next Steps

- [ ] Mirror the outer slot to the left side.
- [ ] Choose the aluminium stock or the machining supplier for the monoblock,
      and add it to the parts list.
- [ ] Check that the lower base does not change the Z travel or the machine
      boundary.

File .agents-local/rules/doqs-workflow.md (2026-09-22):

# DOQS workflow

Qarve design-session checklist and validator commands.

## Before closing a design task

- [ ] SysML / params / BOM updated as needed (requirements only in SysML).
- [ ] If a first-level content directory was added, `python doqs/scripts/apply_licenses.py`
- [ ] `python cad/fingerprint_models.py` if any `.FCStd` was saved, then commit model and measurement together
- [ ] `python doqs/doqs.py generate` if anything generated changed, then read the diff
- [ ] `python doqs/doqs.py check`
- [ ] Submodule `doqs/` present and up to date (`bash setup-tooling.sh` from the repo root; do not commit dirty gitlinks unless freezing a pin)
- [ ] Conventional commit message (`cad`, `arch`, `okh`, `params`, `interface`, `build`, …)

## Modules

- Qarve is currently a single top-level module; `modules/` is empty until sub-assemblies are added.
- Every module folder has: `bom/`, `cad/`, `architecture/`, `docs/`, `manufacturing/`, `modules/`.
- Adapters under `modules/adapters/` for interface version bridges.
- Future extraction to separate repos: see `doqs/docs/architecture.md` (Mode B).

## Interfaces

Breaking port changes bump interface **major** version in SysML name and OKH `version`. Plan adapter modules when needed.

## Builds

Physical machines: `builds/<id>/build.toml` pins the base repo and, when sub-modules exist, each module version and parametric `model`. Record changes in `[[modification]]`.

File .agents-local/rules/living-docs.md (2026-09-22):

# Qarve living documentation

Repo-specific paths and update triggers. Shared rules:
[`.agents/rules/living-docs.md`](../../.agents/rules/living-docs.md).

## Narrative docs

| Location | Purpose | Update when |
| --- | --- | --- |
| `docs/log/YYYY-MM-DD_topic.md` | Activity log (any role) | A working session worth recording |
| `docs/mistakes/YYYY-MM-DD_topic.md` | Incidents | After mistakes (skill: [`.agents/skills/mistake-log/SKILL.md`](../../.agents/skills/mistake-log/SKILL.md)) |
| `docs/decisions/` | ADRs | Non-trivial choices (template: [`.agents/templates/adr.md`](../../.agents/templates/adr.md)) |
| `.agents-local/skills/patterns/SKILL.md` | Reusable agent patterns | New project-specific pattern |
| `docs/onboarding.md` | Setup and validation | Tooling or workflow changes |
| `docs/architecture.md` | Human overview (SysML remains authoritative) | Layout or major modules change |

Use the shared [`log`](../../.agents/skills/log/SKILL.md) skill when adding log entries.
Update `docs/log/README.md` index when adding a file.

## System model (`architecture/`)

| Location | Purpose | Update when |
| --- | --- | --- |
| `architecture/*.sysml` | Machine requirements, composition | System scope changes |
| `modules/*/architecture/*.sysml` | Module requirements, ports | Module behaviour or interfaces change |

Also update `okh.toml` `[[provides-interface]]` / `[[consumes-interface]]` when ports change.

## Generated artefacts

Regenerate — do not hand-edit:

- `graph/usage-graph.json` — `python doqs/doqs.py generate`
- Root `bom/bom.csv` — `python bom/aggregate_bom.py`
- `cad/params.csv` — `python doqs/scripts/resolve_params.py <model>`
- `cad/**/*.fingerprint.json` — `python cad/fingerprint_models.py`

Generic stubs: [`.agents/bootstrap/docs/`](../../.agents/bootstrap/docs/).

If living-doc folders are missing, bootstrap from [`.agents/bootstrap/docs/`](../../.agents/bootstrap/docs/).

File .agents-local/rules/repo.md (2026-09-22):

# Qarve repository profile

Agent-only. Humans: see `README.md` and `docs/onboarding.md`.

## What this repository is

Qarve is an open-hardware modular CNC machine using the [DOQS](https://github.com/refaqt/doqs)
documentation system. The repository root is the **top-level DOQS module**; sub-assemblies will
live under `modules/` when added (empty today).

Shared agent kit: [refaqt/refaqt-agents](https://github.com/refaqt/refaqt-agents) at `.agents/`.
DOQS validators and templates: `doqs/` submodule.

## Where things go

| You are adding | It goes in |
| --- | --- |
| A day's work write-up | `docs/log/YYYY-MM-DD_topic.md` |
| Why a choice was made | `docs/decisions/YYYY-MM-DD_topic.md` |
| Something that went wrong | `docs/mistakes/YYYY-MM-DD_topic.md` |
| System requirements | `architecture/*.sysml` |
| Module requirements | `modules/*/architecture/*.sysml` |
| FreeCAD geometry | `cad/` (manual edits only) |
| Parameters | `cad/params/*.csv` → `doqs/scripts/resolve_params.py` |
| Physical machine lockfile | `builds/<id>/build.toml` |
| Licence texts / overview | `LICENSES/`, root `LICENSE`, `TRADEMARKS.md` |
| A reusable coding pattern | `.agents-local/skills/patterns/SKILL.md` |

## doqs references

| Read | When |
| --- | --- |
| `doqs/docs/architecture.md` | New modules, versioning, interfaces, builds, licensing |
| `doqs/docs/readiness-levels.md` | OTRL / ODRL in `okh.toml` |
| `doqs/docs/naming.md` | Naming modules, parts, interfaces |
| `doqs/docs/using-doqs.md` | What to run, what each gate checks, how CI is set up |
| `doqs/docs/agent-cad.md` | FreeCAD models, fingerprints, the agent-CAD guard |
| `doqs/templates/` | Log, ADR, mistake, OKH entry templates |

`docs/architecture.md` is a short overview — SysML remains authoritative.

Before non-trivial work, read `docs/architecture.md`, then **`doqs/docs/architecture.md`**
(run `bash setup-tooling.sh` from the repo root if `doqs/` is empty). Read relevant `architecture/*.sysml`.

## Stack and execution

- **SysML** in `architecture/` and, when present, `modules/*/architecture/`.
- **FreeCAD** 1.1+ with Assembly workbench; parameters via `cad/params/*.csv` and `doqs/scripts/cad_sync_params.py`. Models are drawn by hand and measured with `cad/fingerprint_models.py`.
- **OKH** manifests: `okh.toml` per module; validate with `python doqs/doqs.py check`.
- Run commands from the **repository root**.
- If `doqs/` or `.agents/` is empty: `bash setup-tooling.sh` from the repo root (agents, any OS). Humans on Windows may double-click `setup-tooling.bat`.
- Before new solutions, read `.agents-local/skills/patterns/SKILL.md` and use the
  `maintain-patterns` skill.

## Hard rules

1. **Never edit `.FCStd` files** — geometry changes happen in FreeCAD manually.
2. **Requirements live in SysML** (`architecture/`) — do not duplicate as standalone requirement docs.
3. **Run every check** after OKH, licence, build, or CAD changes: `python doqs/doqs.py check`.
4. **Prefer** CSV/TOML/SysML output; validate before commit.
5. For OTRL/ODRL or naming, read `doqs/docs/readiness-levels.md` and `doqs/docs/naming.md`.
6. After adding a first-level content directory, run `python doqs/scripts/apply_licenses.py`. Do not run it against `.agents/` or `doqs/` (tooling submodules).
7. **After a model is saved in FreeCAD**, run `python cad/fingerprint_models.py` and commit the `.FCStd` together with its `.fingerprint.json`. See `docs/decisions/2026-09-22_fingerprints-for-hand-drawn-models.md`.

## Validate

```bash
python doqs/doqs.py check
```

`check` runs the seven gates plus the generated-file checks, and it is what CI runs.
After changing anything generated, write the generated files again and read the diff:

```bash
python doqs/doqs.py generate
```

## Branching

Every task that changes the repo must start on a **new git branch** off `main`, unless the user explicitly says otherwise. Do not land task work as commits directly on `main`.

## Conventions

- **Commits:** `<type>(<scope>): <description>` — `feat`, `fix`, `docs`, `cad`, `arch`, `okh`,
  `firmware`, `chore`, `refactor`, `interface`, `model`, `build`, `params`
- Qarve is currently a single top-level module; `modules/` is reserved for future sub-assemblies.

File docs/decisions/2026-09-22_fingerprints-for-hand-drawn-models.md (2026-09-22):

# ADR — Measure hand-drawn FreeCAD models instead of rebuilding them

- **Date:** 2026-09-22
- **Status:** Accepted

## Context

Every FreeCAD document in this repository needs a small measurement file beside
it, called a fingerprint. The automatic checks refuse a model without one. The
measurement records the size, the position and the volume of each object, so a
change to the geometry shows up as readable text in a pull request instead of
hiding inside a binary file.

DOQS writes that file as a side effect of rebuilding a part from its parameters:

```powershell
FreeCADCmd cad/build_model.py
```

Qarve does not work that way. The geometry is drawn by hand in the FreeCAD
window, and hard rule 1 in the agent guide says it stays that way. There is no
build script that could produce these 44 documents, and writing 44 of them by
hand would be a large piece of work that changes how the machine is designed.

Without a decision, the repository could never pass its own checks.

## Decision

Measure the saved file instead of rebuilding it.

`cad/fingerprint_models.py` opens each document in its own FreeCAD process,
measures what the file holds, and writes the fingerprint beside it. It never
saves a `.FCStd`. Geometry keeps changing only in the FreeCAD window, by hand.

Two details matter.

**The measurement describes the saved file, not a refreshed version of it.**
FreeCAD marks a document as changed while it loads a linked part, even when no
geometry moved. The script clears that flag so the measurement counts as coming
from the saved file, which is exactly what it is.

**A document that no longer agrees with itself is reported, not corrected.**
After measuring, the script refreshes the document in memory and compares. If
the geometry moves, the saved file no longer matches its own sketches and
joints. The script names those documents at the end of its run. Only a person
can fix that, in FreeCAD.

## Consequences

- After you save a model in FreeCAD, run `python cad/fingerprint_models.py`
  before you commit. The checks fail if the measurement and the model disagree.
- The measurement is tied to the exact bytes of the `.FCStd`. Saving the model
  again always means writing the fingerprint again.
- If Qarve ever adds parametric parts with a build script, those parts use the
  DOQS route and this script leaves them alone: it writes the same file in the
  same place.
- The script needs FreeCAD 1.1 on the computer that runs it. The build server
  only reads the committed files and does not need FreeCAD.

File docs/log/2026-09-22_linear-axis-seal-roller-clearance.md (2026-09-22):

# 2026-09-22 — Linear axis reworked around the steel strip seal

**Role(s):** engineering, cad

## What happened

Two rounds of manual work in `cad/architecture/machine.FCStd`, body `Linear axis`.

### Round 1 — more room inside the profile

- The axis profile is now 210 mm wide instead of 195 mm.
- The two rail carriages moved 2.5 mm closer to the centre line each. Their spacing
  went from 133 mm to 128 mm.
- Together this gives 14 mm of free space between the outer wall and each rail
  carriage, instead of 4 mm before.
- The drive block in the middle keeps its 86 mm width and sits on the new centre
  line at 105 mm.

### Round 2 — the seal itself

- The top of the base is now closed. The steel strip seal is drawn lying across it:
  170.5 mm long and 0.1 mm thick, held by a lip at each end.
- The side walls moved. Their inner faces are now at 23 mm and 187 mm, instead of
  10 mm and 200 mm. The outer faces sit at 0 mm and 210 mm.
- The bottom corners of the base got a relief, 11.5 mm wide and 5 mm high.
- The seal pocket drawn in round 1 is gone. The strip now runs over the closed top
  instead of inside a side pocket.
- New parts on the left inner wall only: a plate 0.4 mm thick and 8 mm tall, and a
  block 10 mm wide and 13.5 mm tall with chamfered corners.
- The four seal rollers are now 10 mm and 9.8 mm across, instead of 14 mm and
  13.8 mm. The two outer rollers moved 2 mm further apart and 2 mm down. The two
  inner rollers moved 2 mm up. The strip now runs a flatter path.

The machine footprint, enclosure, boundary, top view and both rotary-axis bodies
were not touched. The overall size of the linear axis stayed 210 mm by 60 mm.

## Open question

The stated goal was to fit **larger** rollers. The drawing now shows **smaller**
rollers. Confirm which diameter is the one we build.

## Next Steps

- [ ] Confirm the roller diameter, then pick the supplier and add the roller to the parts list.
- [ ] Name the two new parts on the left inner wall, so the drawing is readable.
- [ ] Check whether the 15 mm of extra width changes the machine footprint and the enclosure.
- [ ] Mirror the new left-side parts to the right side, if the design needs them on both sides.

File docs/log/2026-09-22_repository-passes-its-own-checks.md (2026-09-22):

# 2026-09-22 — The repository passes its own checks again

**Role(s):** engineering, software

## What happened

The automatic checks on every pull request had been failing. Three separate
problems were behind it, and none of them was about the machine design.

**The FreeCAD models had no measurements.** Every model needs a small
measurement file beside it, so that a change to the geometry can be read as text
in a pull request. All 44 models were missing theirs, so all 44 failed. They now
have them. How they are produced, and why this repository cannot use the usual
route, is in a separate decision note.

**The example machine record described a machine that does not exist.** It was
marked "Example Workshop" and "Scaffold", and it pointed at a version tag that
was never created. A machine record is meant to say what really went into one
real machine, so this one was removed. The blank example that people copy from
is still there.

**The build server called a tool that had been renamed.** The checking tools
were updated on 1 September, and three of them changed name. The build server
still used an old name, which now stops with an error instead of running. The
build server, the README and the setup guide now use one command,
`python doqs/doqs.py check`, which is also the command to run before you commit.

## Two things that need a person

**Three models no longer agree with their own sketches and joints.** When FreeCAD
refreshes them, parts move. The measurement files record what the saved files
hold, which is correct, but somebody should open these three in FreeCAD, refresh
them, check the result and save:

- `cad/architecture/linear-axis-configuration.FCStd` — one sketch moves 5 mm
- `cad/assemblies/linear-motor-z/linear-motor-z.FCStd` — the motor parts move
- `cad/assemblies/x-axis/x-axis.FCStd` — two guide blocks move 32 mm

This is most likely a side effect of the linear axis work on this branch: those
assemblies use the parts that changed.

**A fault in the shared tools was fixed in the shared tools.** Three models hold
a stress analysis, and the measuring tool could not read any of them. It treated
an analysis mesh as geometry and gave up on the whole document. That was fixed in
the shared tools repository, not here, so every machine project gets the fix:
[refaqt/doqs#34](https://github.com/refaqt/doqs/pull/34). That pull request still
needs to be merged. Once it is, `bash setup-tooling.sh` brings it into this
working copy. The measurements already in this repository were taken with the fix
in place and do not need redoing.

## Next Steps

- [ ] Open the three models listed above in FreeCAD, refresh them, check the result and save.
- [ ] Run `python cad/fingerprint_models.py` after saving them, then commit both the models and their measurements.
- [ ] Merge [refaqt/doqs#34](https://github.com/refaqt/doqs/pull/34), then run `bash setup-tooling.sh` here.

## Related

- [2026-09-22_fingerprints-for-hand-drawn-models.md](../decisions/2026-09-22_fingerprints-for-hand-drawn-models.md)
- [2026-09-22_linear-axis-seal-roller-clearance.md](2026-09-22_linear-axis-seal-roller-clearance.md)

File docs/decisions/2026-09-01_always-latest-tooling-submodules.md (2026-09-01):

# ADR — Always-latest tooling submodules

- **Date:** 2026-09-01
- **Status:** Accepted

## Context

`doqs/` and `.agents/` are tooling submodules. Agents and humans were told to `git submodule update --init --recursive`, which checks out the **recorded pin**. CI should stay on that pin, but daily work (humans, Claude Code, cloud agents) should see latest `main` of the shared kits without committing a gitlink bump after every fetch.

doqs must not write consumer-root files (`AGENTS.md`, `README.md`, `setup-tooling.*`). First-step wording for agents lives in [refaqt-agents](https://github.com/refaqt/refaqt-agents) templates.

## Decision

- Copy-once helpers `setup-tooling.sh` and `setup-tooling.bat` live at this **repo root** (templates in `doqs/templates/setup-tooling/`). They run `git submodule sync --recursive` then `git submodule update --init --recursive --remote`.
- `.gitmodules` sets `branch = main` only on tooling submodules (`doqs`, `.agents`). Extracted machine modules stay SHA-pinned without `branch`.
- **All agents, any OS:** `bash setup-tooling.sh`. **Humans on Windows** may double-click `setup-tooling.bat` (`pause` is OK there only). Agents must not run the `.bat`.
- Do not commit dirty submodule gitlinks after `--remote` unless freezing a pin. GitHub Actions keep `submodules: recursive` (recorded pin).
- `setup-tooling.sh` is stored with LF (`setup-tooling.sh text eol=lf` in `.gitattributes`).

## Consequences

- Working tree tracks latest `main` of the kits after the helper runs; the committed gitlink remains a pin for CI and clones that skip the helper.
- New machine repos copy the helpers from doqs templates to their own root; they never run them from `doqs/templates/setup-tooling/`.
- `AGENTS.md` first-step text is maintained in refaqt-agents and prepended here.

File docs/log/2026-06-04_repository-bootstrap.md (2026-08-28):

# 2026-06-04 — Repository bootstrap

**Role(s):** engineering

## Goal

Initialize the Qarve repository per `doqs_architecture.md` and portable Cursor agent kit.

## Work Done

- Root and example modules (`frame`, `x-axis`) with OKH, SysML, BOM, CAD param scripts.
- Embedded `doqs/` validators, templates, schemas.
- Example build lockfile `builds/serial-0042/`.
- `.cursor` rules and skills adapted for DOQS.

## Decisions Made

- See `docs/decisions/2026-06-04_adopt-doqs-layout.md`.

## Open Questions

- [ ] Confirm GitHub org/repo URLs and licence text.
- [ ] Extract `doqs/` to standalone repo vs keep embedded.
- [ ] Initial module set beyond frame + x-axis.

## Next Steps

- [ ] Add FreeCAD assemblies and LFS-tracked binaries.
- [ ] Wire CI to run validators on push.

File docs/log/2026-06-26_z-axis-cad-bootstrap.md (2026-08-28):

# 2026-06-26 — Z-axis CAD bootstrap

**Role(s):** engineering, cad

## What happened

- Extended spindle assembly work and began the z-slide assembly stack in FreeCAD.
- Added CAD parts and assemblies: z-axis assembly, guide-block, guide-rail-z,
  linear-motor forcer/magnets (`.FCStd` plus `.stp` sources where applicable).
- Committed alongside the guide-rail adjustment FEM setup in
  `simulation/guide-rail-adjustment/`.
- Bumped `doqs/` submodule pointer; excluded regenerable FreeCAD extract artifacts
  (`fcstd-extract/`, `*.zip`) via `.gitignore`.

## Next Steps

- [ ] Continue z-axis assembly integration and parametric joints.
- [ ] Register new parts in `okh.toml` when geometry stabilizes.

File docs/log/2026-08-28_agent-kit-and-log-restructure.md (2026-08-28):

# 2026-08-28 — Agent kit and log restructure

**Role(s):** engineering

## What happened

- Completed refaqt-agents ADR follow-through: slimmed `AGENTS.md` to a thin discovery stub;
  moved repo-specific rules to `.agents-local/rules/`.
- Slimmed `.cursor/rules/*.mdc` to pointer-only adapters (plus globs where needed).
- Migrated `docs/dev-log/` → `docs/log/` with mandatory **Role(s):** on every entry.
- Retired `docs/prompts-log/`; folded substantive prompts-log content into log entries
  (FEM workflow, x-axis Params pattern, spindle-clamp trade-offs, guide-rail FEM fix).
- Removed prompts-log skill, rule, and `.claude/skills/prompts-log` symlink.
- Added ADR superseding ADR-002 item 16:
  `docs/decisions/2026-08-28_migrate-to-unified-log.md`.

Reference: [aqtuator PR #12](https://github.com/refaqt/aqtuator/pull/12) and
`docs/decisions/2026-08-27_unify-agent-kit-via-refaqt-agents.md` in aqtuator.

## Decisions

- Qarve uses unified `docs/log/` per refaqt-agents; no prompts-log.
- Session logging uses the shared `log` skill when work is worth recording.

## Next Steps

- [ ] Bump `doqs/docs/agent-guide.md` separately if DOQS spec still references dev-log/prompts-log paths.

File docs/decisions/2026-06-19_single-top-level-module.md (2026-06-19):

# ADR-002 — Single top-level module (defer sub-assemblies)

- **Date:** 2026-06-19
- **Status:** Accepted

## Context

Qarve was bootstrapped with example sub-modules (`modules/frame`, `modules/x-axis`) to demonstrate DOQS multi-module composition. Early development is simpler as one repository and one top-level module. Hardware sub-modules may later live under `modules/` and optionally be extracted to separate repositories.

The `doqs/` Git submodule (shared tools and specification) remains unchanged.

## Decision

- Operate Qarve as a **single top-level DOQS module** at the repository root.
- Remove example scaffolds under `modules/frame` and `modules/x-axis`.
- Keep `modules/` (and `modules/adapters/`) as placeholders for future sub-assemblies.
- Root `okh.toml` has no `[[hasComponent]]` entries until real sub-modules are added.
- Build lockfiles pin `[base]` only until sub-modules exist.

## Consequences

- `architecture/machine.sysml` holds machine-level requirements only; no sub-module imports until added.
- Agents and docs should not assume active sub-modules under `modules/`.
- Adding the first sub-assembly follows `modules/README.md` and `doqs/docs/architecture.md`.
- Extraction to separate repos remains a future option (DOQS Mode B); not implemented now.

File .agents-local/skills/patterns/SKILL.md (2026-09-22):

---
name: project-patterns
description: >-
  Reusable DOQS/Qarve patterns — parametric CAD, validators, FreeCAD master
  sketches, OKH from BOM. Load before implementing or after a novel fix.
---

# Project patterns (Qarve / DOQS)

Reusable patterns specific to this repository. Check before implementing; update when a pattern changes.

## Resolve parametric model before CAD sync

**When to use:** Changing dimensions for a named model (default, 500mm, …) on a module that has `cad/params/`.

**Pattern:**

```powershell
# From repo root for top-level CAD, or modules/<name>/ for a sub-assembly
python doqs/scripts/resolve_params.py 500mm
# Then inside FreeCAD: exec(open("doqs/scripts/cad_sync_params.py").read())
```

**Gotchas:** `cad/params.csv` is gitignored — never edit by hand. Every alias must exist in `default.csv`. Both tools live in the `doqs/` submodule and update with it. A copy of either inside a `cad/` folder is a hard failure of the checks. Qarve has no `cad/params/` yet, so this pattern applies to the first module that gets one.

**Last used:** 2026-06-04 repository bootstrap

## Validate before commit

**When to use:** After editing any `okh.toml`, build lockfile, or SysML import.

**Pattern:**

```powershell
python doqs/doqs.py check
```

**Gotchas:** Run from repository root. `doqs/` must be initialized as a submodule at `qarve/doqs/`. `check` also fails when a generated file is stale — write them again with `python doqs/doqs.py generate` and read the diff. After adding a first-level content directory, run `python doqs/scripts/apply_licenses.py` first; it must not rewrite `.agents/` or `doqs/`.

**Last used:** 2026-09-22 repository passes its own checks

## Measure a FreeCAD model after saving it

**When to use:** After you save any `.FCStd` in FreeCAD, before you commit.

**Pattern:**

```powershell
python cad/fingerprint_models.py
```

**Gotchas:** Needs FreeCAD 1.1 on the machine that runs it. It never saves a `.FCStd`. Commit the model and its `.fingerprint.json` in the same commit, or the check fails. The run ends by naming any document whose geometry moves when FreeCAD refreshes it — those need a person to open, refresh and save. Reasons: `docs/decisions/2026-09-22_fingerprints-for-hand-drawn-models.md`.

**Last used:** 2026-09-22 repository passes its own checks

## SysON session over architecture/*.sysml

**When to use:** Viewing or editing Qarve SysML graphically.

**Pattern:**

```powershell
# Humans: double-click syson.bat (or bash syson.sh)
# Agents:
python doqs/scripts/syson.py ui
```

Control panel at `http://127.0.0.1:8765`: Open, Save, Reload, Stop, Status.

**Gotchas:** Docker Desktop must be running. Homepage **Download** is a JSON zip, not SysML — always **Save**. **Reload** re-imports from git and drops diagrams. Canonical files stay in `architecture/*.sysml`. SysON export can drop comments and unresolved types (`Real`); review `git diff`. Guide: `doqs/docs/syson.md`. Agents must not run `syson.bat`.

**Last used:** 2026-09-01 SysON control panel

## FreeCAD master sketches in Body_master

**When to use:** Top-down CAD where an assembly `.FCStd` drives child part geometry via `SubShapeBinder`, and a part fails to appear in Assembly **Insert**.

**Pattern:**

- In the assembly file: `Master sketches` group → `Body_master` (`PartDesign::Body`) → sketches constrained to **Body origin planes**.
- Child parts: `SubShapeBinder` → sketches inside `Body_master` (not Assembly origin planes).
- Assembly object holds joints and inserted part links only.

**Gotchas:** Binder from part back to assembly document creates a cycle (assembly → part → assembly). Do not constrain master sketches to `Assembly` origin planes. See `doqs/docs/decisions/2026-06-24_freecad-master-sketches-body.md`.

**Last used:** 2026-06-23 spindle clamp design

## OKH parts from BOM

**When to use:** Agent asked to add manufactured parts to a module manifest.

**Pattern:** Point agent at `<module>/bom/bom.csv` and template `doqs/templates/okh-module-with-parts.toml`.

**Gotchas:** Do not invent geometry — no `.FCStd` edits by agents.

**Last used:** 2026-06-04 repository bootstrap

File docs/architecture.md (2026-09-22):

# Architecture overview (Qarve)

**Qarve** is the top-level DOQS machine module in this repository. It is currently a **single module** at the repo root; `modules/` is reserved for future sub-assemblies.

The **canonical** DOQS specification (modularity, versioning, interfaces, OKH, builds, FreeCAD params, agent workflow) lives in the **`doqs/` submodule**:

→ **[doqs/docs/architecture.md](../doqs/docs/architecture.md)** (from [github.com/refaqt/doqs](https://github.com/refaqt/doqs))

Also in the submodule:

| Doc | Topic |
| --- | --- |
| [doqs/docs/readiness-levels.md](../doqs/docs/readiness-levels.md) | OTRL / ODRL for `okh.toml` |
| [doqs/docs/naming.md](../doqs/docs/naming.md) | Naming conventions (draft) |
| [doqs/docs/using-doqs.md](../doqs/docs/using-doqs.md) | What to run, and what each check looks at |

## This repo (summary)

| Path | Role |
| --- | --- |
| `architecture/machine.sysml` | Machine composition and system requirements |
| `modules/` | Reserved for sub-assemblies (see [modules/README.md](../modules/README.md)) |
| `builds/` | Physical machine lockfiles |
| `LICENSE` / `LICENSES/` | Split-licence overview and full legal texts (CERN-OHL-S / GPL / CC BY-SA) |
| `TRADEMARKS.md` | Reserved organisation and project marks |
| `graph/usage-graph.json` | Reverse usage (generated) |
| `doqs/` | Git submodule — tools + spec |

For multi-module composition and future extraction to separate repos, see `doqs/docs/architecture.md`.

## Authoritative model

Requirements and interfaces: **`architecture/*.sysml`** and, when present, **`modules/*/architecture/*.sysml`** — not this markdown file.

Graphical editing: double-click `syson.bat`, then **Open** / **Save** (see `doqs/docs/syson.md`).

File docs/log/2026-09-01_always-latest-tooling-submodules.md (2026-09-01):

# 2026-09-01 — Always-latest tooling submodules

**Role(s):** engineering

## What happened

Added copy-once root helpers `setup-tooling.sh` / `setup-tooling.bat` so agents and humans fetch latest `main` of `doqs/` and `.agents/` after clone. Set `branch = main` on those tooling submodules. Prepended **First step (required)** to `AGENTS.md` (agents: `bash setup-tooling.sh`; humans on Windows may double-click the `.bat`). Swept leftover `git submodule update --init` lines in onboarding, `repo.md`, and `doqs-workflow.md`. CI still checks out the recorded pin.

## Decisions

Working tree tracks `main` via the helper; gitlinks stay pins unless we freeze one. Helpers are copied from doqs templates, not written by doqs scripts. See [2026-09-01_always-latest-tooling-submodules.md](../decisions/2026-09-01_always-latest-tooling-submodules.md).

## Next Steps

Commit per repo when asked; do not push unless asked. Do not commit dirty submodule gitlinks after a local helper test.

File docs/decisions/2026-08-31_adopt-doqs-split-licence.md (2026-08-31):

# ADR — Adopt DOQS split-licence layout

- **Date:** 2026-08-31
- **Status:** Accepted

## Context

ADR-001 adopted the DOQS modular layout and left the full CERN-OHL licence text
as a placeholder in the root `LICENSE` file. DOQS now specifies a **content-type
split** at each Git repository root, not a single blanket licence:

| Content | Directories | Licence |
| --- | --- | --- |
| Hardware | `cad/`, `architecture/`, `manufacturing/`, `bom/`, `builds/`, `modules/` | CERN-OHL-S v2.0 |
| Firmware & software | `firmware/`, `software/`, `simulation/` | GPL-3.0 |
| Media & documentation | `docs/`, `measurement/` | CC BY-SA 4.0 |

Templates and validators live in `doqs/scripts/apply_licenses.py` and
`doqs/scripts/validate_licenses.py`.

## Decision

Qarve follows that layout:

- Root `LICENSE` is an overview mapping directories to licences.
- Full legal texts live in `LICENSES/`.
- `TRADEMARKS.md` reserves the organisation and project names/logos.
- Each mapped first-level directory that exists carries a short `LICENSE` stub.
- Root `okh.toml` keeps `license = "CERN-OHL-S-2.0"` (OKH describes the hardware
  project) with a comment pointing at the split.
- README has a Licence section naming all three licences.

Tooling submodules (`doqs/`, `.agents/`) and generated `graph/` are outside the
mapping and do not get directory stubs.

## Consequences

- New first-level content directories need `python doqs/scripts/apply_licenses.py`
  before `validate_all.py` will pass.
- `apply_licenses.py` must not be pointed at `.agents/` or `doqs/`.
- This closes the “full CERN-OHL text still to be finalized” item from ADR-001
  (`docs/decisions/2026-06-04_adopt-doqs-layout.md`).

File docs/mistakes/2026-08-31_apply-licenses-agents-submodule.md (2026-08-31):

# 2026-08-31 — apply_licenses wrote into .agents

## What happened

Running `python doqs/scripts/apply_licenses.py` from the machine root wrote a
CERN-OHL-S machine licence kit into the `.agents/` submodule (refaqt-agents),
overwriting its GPL `LICENSE`. The files were reverted; `.agents/` was left clean.

## Why it went wrong

`iter_submodule_paths` treated every non-`doqs` Git submodule as an extracted
machine module. Qarve also mounts [refaqt-agents](https://github.com/refaqt/refaqt-agents)
at `.agents/`, which is tooling, not a module (no `okh.toml`).

## Prevention rule

After `apply_licenses.py`, confirm `.agents/` and `doqs/` are unmodified.
`apply_licenses.py` / `validate_licenses.py` must skip tooling submodules
(`doqs/`, `.agents/`) and any submodule without `okh.toml`.

## Related

- `docs/decisions/2026-08-31_adopt-doqs-split-licence.md`
- doqs commit `a472e09` (`cursor/skip-agents-licence-scan-3e45`)

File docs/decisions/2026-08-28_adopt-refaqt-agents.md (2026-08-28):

# ADR-002 — Adopt refaqt-agents shared kit

- **Date:** 2026-08-28
- **Status:** Accepted (partially superseded — see [2026-08-28_migrate-to-unified-log.md](2026-08-28_migrate-to-unified-log.md))

## Context

Qarve already had machine-local `.cursor/rules/` and skills copied or adapted from a generic bootstrap. Refaqt is standardizing cross-repo agent guidance in [refaqt-agents](https://github.com/refaqt/refaqt-agents), mounted at `.agents/` (see [aqtuator](https://github.com/refaqt/aqtuator) as reference).

## Decision

- Add `.agents/` Git submodule for shared rules and process skills.
- Keep Qarve/DOQS-specific behaviour in `.agents-local/` (patterns, prompts-log, DOQS skill symlinks) and scoped `.cursor/rules/` (doqs-workflow, freecad, sysml-okh, prompts-log).
- Restructure root `AGENTS.md` as the single entry point; add `CLAUDE.md` importing it for Claude Code.
- Add `.claude/skills/` symlinks mirroring shared and local skills.
- Retain DOQS narrative paths (`docs/dev-log/`, `docs/prompts-log/`) — do not migrate to refaqt-agents `docs/log/`.

## Consequences

- Generic workflow updates flow from refaqt-agents (bump submodule pointer); Qarve-only rules stay in this repo.
- `.cursor/skills/` is removed; skills load from `.agents/` and `.agents-local/` paths listed in `AGENTS.md`.
- `docs/skills.md` becomes a pointer to `.agents-local/skills/patterns/SKILL.md`.
- `doqs/docs/agent-guide.md` may be updated separately to document the three-layer model.

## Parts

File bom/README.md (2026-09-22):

# Top-level bill of materials

`bom.csv` at this path is **generated** by `doqs/scripts/aggregate_bom.py` from every `**/bom/bom.csv` under the repo (typically under `modules/` when sub-assemblies exist). Do not edit it by hand.

```powershell
python doqs/doqs.py generate
```

Module-level `bom/bom.csv` files are source data and are committed.

The aggregating tool lives in the `doqs/` submodule and updates with it. A copy of it in this folder would go out of date without anybody noticing, so there is none.

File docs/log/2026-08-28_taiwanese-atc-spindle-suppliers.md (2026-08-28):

# 2026-08-28 — Taiwanese ATC spindle supplier research

**Role(s):** engineering

## Goal

Identify Taiwanese spindle suppliers and catalog models matching Qarve spindle requirements:

| Criterion | Requirement |
|---|---|
| Tool interface | ATC; ISO20 or larger, or HSK |
| Power | > 1.1 kW |
| Min speed | < 3000 rpm (low-speed capability) |
| Max speed | > 23,000 rpm |
| Torque | > 0.94 Nm |

## Work Done

- Searched public catalogs and datasheets for Taiwan spindle manufacturers.
- Mapped published models against power, speed range, torque, taper, and ATC capability.
- Flagged gaps where min speed or torque are not published online.

**Note:** Min speed < 3000 rpm is the binding constraint. Many Taiwan high-frequency (HF) built-in spindles publish minimum speeds of 6,000–10,000+ rpm. For ISO20-class spindles, verify low-speed torque and cooling with the vendor before selecting.

## Suppliers and candidate models

### 1. 普慧 Parfaite Tools — Taichung area

Website: https://parfaite.com/

| Model | Taper | Power | Torque | Speed range | Meets spec? |
|---|---|---|---|---|---|
| [EIA0820-30](https://parfaite.com/en/product/eia0820-30/) | ISO20 | 2.0 kW | 1.1 Nm | 10,000–30,000 rpm | Min speed too high |
| [EIA0845-50](https://parfaite.com/en/product/eia0845-50/) | ISO10/15T/HSK25E | 4.5 kW | 1.1 Nm | 20,000–50,000 rpm | Min speed too high |
| [MIA1275-24](https://parfaite.com/en/product/mia1275-24/) | BT30 / HSK40E | 7.5 kW | 6.0 Nm | 6,000–24,000 rpm | Max OK; min speed high |
| [MIA1291-30](https://parfaite.com/en/product/mia1291-30/) | HSK40E / BT30N | 9.1 kW | 6.5 Nm | 7,500–30,000 rpm | All except min speed |

Best Parfaite pick for ISO20 + torque: **EIA0820-30** — only misses low-speed requirement on paper.

### 2. 矩將科技 MicroLab — Taichung

Website: https://www.twspindle.com/  
Contact: microlab@twspindle.com · +886-4-22392345

| Model | Taper | Power | Max rpm | ATC | Notes |
|---|---|---|---|-----|---|
| [M2-QMS](https://www.twspindle.com/zh-TW/product/built-in-motor-high-speed-spindle-diameter-80_M2-QMS.html) | ISO20 | 2 kW | 36,000 | Pneumatic | Torque/min speed not published — RFQ |
| M25-GMSA / M25-GMSA-FG | ISO25 | 3.7 kW | 30,000 | Pneumatic/oil | Same |
| H3-GMSA-FG | HSK32E | 3.7 kW | 24,000 | Pneumatic | HSK option |

Good candidate for compact ISO20 ATC (Ø80); confirm VFD low-speed torque with vendor.

### 3. 釸達精密 Theta Precision — Taichung (Dayi)

Website: https://www.theta-spindle.com/

| Model | Taper | Power | Torque (S1) | Max rpm | ATC |
|---|---|---|---|---|-----|
| TH-80.02 | ISO20 | 2.5 kW | **0.7 Nm** | 40,000 | Tool sensors; confirm ATC |
| [TH-100.03](https://www.theta-spindle.com/en/products/th-100-03-3kw-iso-25-30-000rpm-model) | ISO25 | 3 kW | 2.4 Nm | 30,000 | Confirm ATC |
| [TH-100.03](https://www.theta-spindle.com/en/products/th-100-03-3kw-hsk-e32-40-000rpm-model) | HSK-E32 | 3 kW | 2.4 Nm | 40,000 | Confirm ATC |
| [TH-120.03](https://www.theta-spindle.com/en/products/th-120-03-4-6kw-hsk-e40-36-000rpm-model) | HSK-E40 | 4.6 kW | 4.5 Nm | 36,000 | Confirm ATC |
| [TH-120.15](https://www.timtos.com.tw/en/product/D2652059A509F0CCD929D219C19DC84A3E250D31F8B64F7C/info.html) | HSK-E40 | 7.5 kW | 5.9 Nm | 40,000 | ATC standard |

TH-80.02 **fails torque** (0.7 Nm S1). HF base speed typically ~9,700–11,700 rpm; low-speed operation below 3000 rpm unlikely without field weakening.

### 4. 恩德 Anderson Group — Taiwan

Website: https://spindle.anderson.com.tw/

Best documented option for wide speed range on integrated machines (e.g. HSK-63F at **1,000–22,000 rpm**). PMSM line advertises high torque at low speed.

| Model (ATS series) | Taper | Power | Max rpm | Notes |
|---|---|---|---|---|
| AST80L-I20-P | **ISO20** | 4 kW | 40,000 | PMSM; ATC; ask min speed & torque |
| AST80L-E25-P | HSK-E25 | 4 kW | 50,000 | Same |
| AST100L-E32-P | HSK-E32 | 15 kW | 36,000 | Same |
| AST120L-E40-P | HSK-E40 | 20 kW | 30,000 | Same |
| AST150L-F63-P | HSK-F63 | 20 kW | 24,000 | Used on machines at 1000+ rpm min |

Best Anderson pick for full envelope: **AST80L-I20-P** (ISO20) or **AST80L-E25-P** (HSK).

### 5. Spintrue Tech — Taiwan

Website: https://www.spintrue-spindle.com/

Machine-tool grade; HSK-E40 and up (no ISO20 in standard catalog). Custom ODM available.

| Model | Taper | Power | Torque | Max rpm |
|---|---|---|---|---|
| CB34C (CB0 series) | HSK-E40 | 4.6 kW | 6 Nm | 30,000 |

### 6. KENTURN — Changhua (est. 1983)

Website: https://www.kenturn.com.tw/

Large machining-center spindles; HSK-E40+ built-in motors. No ISO20 in public catalog; custom possible.

| Model | Taper | Power | Max rpm |
|---|---|---|---|
| MVB0925 | BBT30 (HSK-E40 category) | 10 kW | 24,000 |
| GVB0520 | ER16 only | 2 kW | 24,000 |

### 7. Paul Jet Hitechnology Corp. — Taiwan

Listed on [MachineTo](https://www.machineto.com/spindle-th-series-pauljet-10154773) with TH series nearly identical to Theta naming (TH-80 ISO20, TH-100 HSK-E32, etc.). Treat as related/OEM channel; cross-check specs with Theta.

## Models that clearly miss one requirement

| Model | Issue |
|---|---|
| Theta TH-80.02 (ISO20) | Torque 0.7 Nm < 0.94 Nm |
| Parfaite EIA0827-40 (ISO20) | Torque 1.0 Nm (borderline) |
| Parfaite EIA0820-30 | Min speed 10,000 rpm |
| Theta TH-170.09 (HSK-A63) | Oversized (18.5 kW) though max 24,000 rpm OK |

## Contact priority

| Priority | Supplier | Rationale |
|---|---|---|
| 1 | Parfaite | Best published ISO20 ATC data (EIA0820-30 hits power/torque/max speed) |
| 2 | Anderson | Best bet for min speed < 3000 rpm with HSK/ISO20 PMSM spindles |
| 3 | MicroLab | Compact ISO20 ATC (Ø80/Ø100); needs torque + min-speed confirmation |
| 4 | Theta | Strong HSK-E32/E40 ATC line if HF min-speed limits acceptable |
| 5 | Spintrue / Kenturn | If stepping up to HSK-E40+ for machining-center class |

## RFQ questions for vendors

1. Minimum continuous speed (not just base frequency speed)
2. Torque at 1000 / 2000 / 3000 rpm (not only at rated power point)
3. ATC interface (drawbar, tool-present sensors, magazine compatibility)
4. Cooling (water/oil) and controller (VFD vs FANUC/closed-loop)
5. Lubrication (grease vs oil-air) — affects max rpm

## Open Questions

- [ ] Is ISO20 mandatory, or are HSK-E32/E40 acceptable?
- [ ] Router-class (VFD) vs machining-center-class (FANUC/closed-loop) spindle?
- [ ] Confirm min speed < 3000 rpm is required for tapping/drilling vs. preference

## Next Steps

- [ ] Shortlist 2–3 models after taper and machine-class decision
- [ ] Send RFQ to Parfaite and Anderson first
- [ ] Capture selected spindle in SysML / BOM when part number is chosen

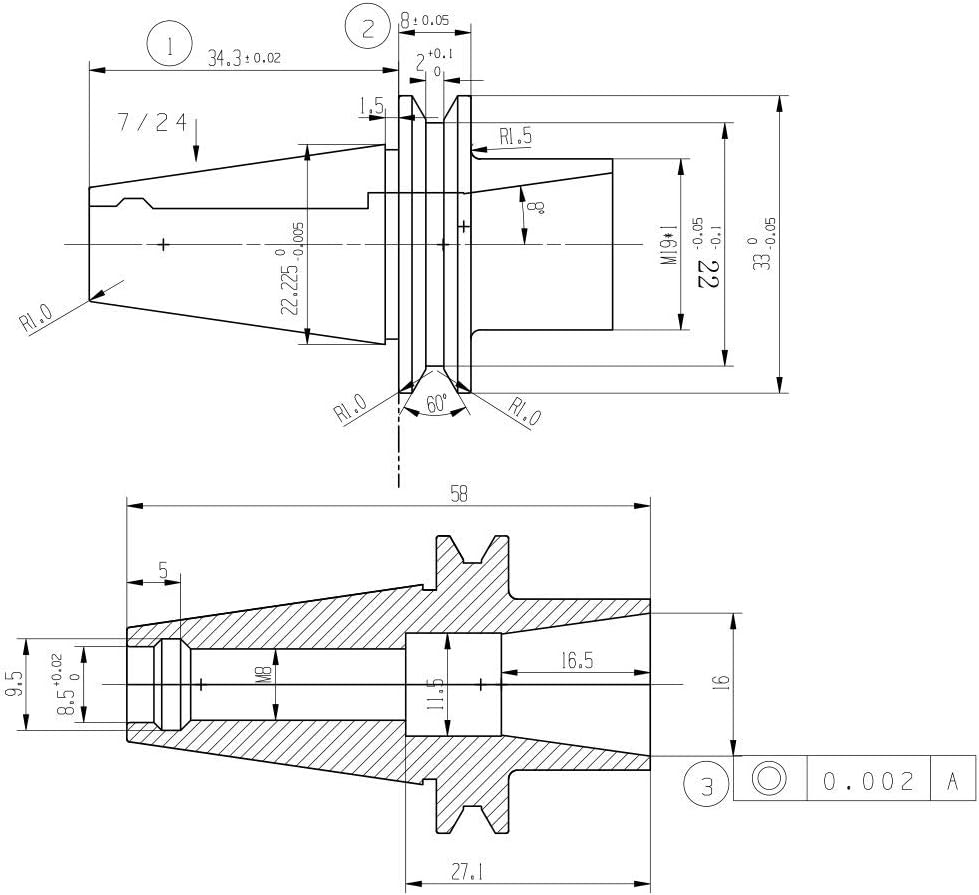
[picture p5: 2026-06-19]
cad/parts/spindle/ISO20-ER16-dimensions.jpg

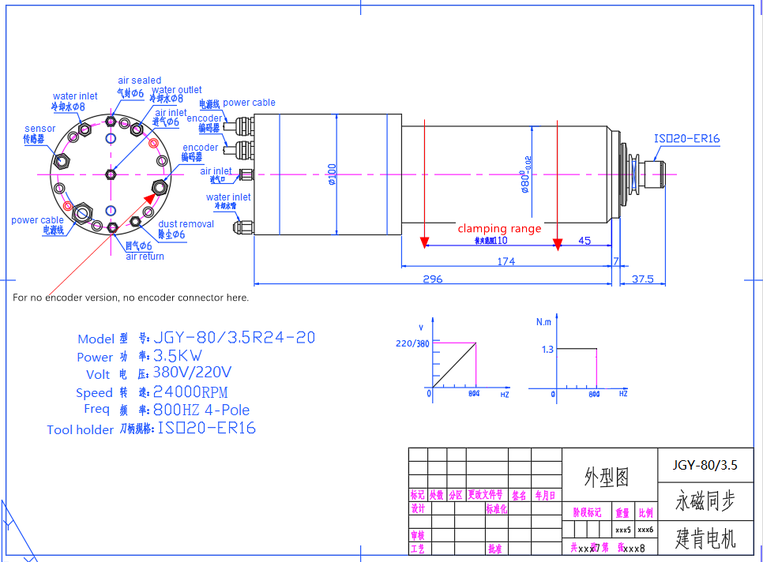
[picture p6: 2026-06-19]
cad/parts/spindle/JGY-80_3.5R24-20.png

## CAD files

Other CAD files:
cad/assemblies/spindle-assembly/spindle-assembly.FCStd
cad/models/spindle-assembly_model.FCStd
cad/models/test-fem/Assembly.FCStd
cad/models/test-fem/Assembly_model.FCStd
cad/architecture/machine.FCStd
cad/assemblies/linear-guide-x/linear-guide-x.FCStd
cad/assemblies/linear-guide-z/linear-guide-z.FCStd
cad/assemblies/linear-motor-z/linear-motor-z.FCStd
cad/assemblies/machine/machine.FCStd
cad/assemblies/spindle-clamp/spindle-clamp.FCStd
cad/assemblies/x-axis/x-axis.FCStd
cad/assemblies/z-axis/z-axis.FCStd
cad/models/test-fem/Part2.FCStd
cad/parts/guide-block/guide-block.FCStd
cad/parts/guide-rail-support-z/guide-rail-support-z.FCStd
cad/parts/guide-rail-x/guide-rail-x.FCStd
cad/parts/guide-rail-z/guide-rail-z.FCStd
cad/parts/linear-encoder-1/linear-encoder-1.FCStd
cad/architecture/linear-axis-configuration.FCStd
cad/architecture/rotary-axis-configuration-3phis.FCStd
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

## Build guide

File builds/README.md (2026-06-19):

# Physical machine builds

Each subdirectory is one real machine instance (serial, prototype, or customer build). `build.toml` pins the machine repo version and, when sub-assemblies exist, each module version and parametric model — like `Cargo.lock` for hardware.

## New build

1. Copy `example-baseline.toml` to `<your-id>/build.toml`.
2. Set `[base]` to the qarve repo and tag. Add `[[module]]` entries when sub-assemblies exist under `modules/`.
3. Run `python doqs/scripts/validate_build.py`.
4. Add photos and `notes.md` for non-standard modifications.

External forks may list themselves in root `known-consumers.toml` for the reverse usage graph.

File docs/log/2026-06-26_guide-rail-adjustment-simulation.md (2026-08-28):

# 2026-06-26 — Guide-rail adjustment simulation

**Role(s):** engineering, simulation

## Goal

Evaluate whether a small bend in the linear guide rail can be corrected by
adjusting the preload of the screws that fix the rail, using a compliant layer
underneath the rail as the adjustment medium.

## Work Done

- Set up an FEM study in `simulation/guide-rail-adjustment/guide-rail-adjustment.FCStd`.
- Modelled a 5 mm POM layer underneath the guide rail that is compressed by the
  preloading of the rail-fixing screws.
- Used the screw preload to locally compress the POM layer so the rail can be
  straightened, simulating correction of a bend in the guide.
- Diagnosed an initial CalculiX failure: the force constraint referenced a sketch
  edge (`Sketch002.Edge5`) rather than meshed `BooleanFragments` geometry, producing
  empty `femnodes_mesh` / edge_table errors. Fix: reference meshed solid faces/edges
  on the fragment compound, not sketch geometry.

## Results

- Results captured in `simulation/guide-rail-adjustment/guide-rail-adjustment.FCStd`.
- The compliant POM layer allows the rail position to be adjusted via differential
  screw preload, supporting the concept of bend correction through preload tuning.

## Notes

- CalculiX solver scratch/output files (`FEMMeshGmsh.*`) are regenerable from the
  `.FCStd` and are excluded from version control via `.gitignore`.

## Next Steps

- [ ] Quantify achievable rail-straightness correction vs. screw preload range.
- [ ] Confirm POM creep/long-term compression does not relax the adjustment.

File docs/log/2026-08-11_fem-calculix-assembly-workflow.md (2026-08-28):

# 2026-08-11 — FEM CalculiX assembly material/mesh workflow

**Role(s):** engineering, simulation

## What happened

Investigated CalculiX `femelement_table` errors on `cad/models/test-fem` with an
Assembly-linked multi-material model (`Assembly_model.FCStd` → BooleanFragments
CompSolid → CompoundFilter → Analysis).

- Reproduced a material coverage gap (2706 mesh volumes vs 2430 assigned). Gmsh
  Solid1/2/3 groups sum correctly when counted manually.
- Confirmed FreeCAD binary solid-node search undercounts CompSolid interface C3D10
  elements; assigning material via empty-reference workaround restores full
  coverage (2706/2706).
- Ran CalculiX on a temp copy: ccx exit 0, `.frd` produced.
- After the material fix, a remaining group-data ERROR in the report is expected
  noise — geometry fallback succeeded and full assignment was verified.

## Decisions

- Keep Assembly.FCStd link intact; fix material assignment in the FEM mesh pipeline
  rather than flattening the assembly prematurely.

## Next Steps

- [ ] Document the empty-reference material workaround in the FreeCAD skill if it
  recurs on other CompSolid assemblies.

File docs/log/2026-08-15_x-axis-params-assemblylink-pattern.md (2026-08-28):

# 2026-08-15 — X-axis Params and AssemblyLink pattern

**Role(s):** engineering, cad

## What happened

Diagnosed broken `linear-guide-x` joints in `x-axis.FCStd`: `Joint005` Distance
expressions could not read `x_axis_position` from linked `x-axis_Params` — Joint005
showed Invalid in the parent assembly.

Root causes:

- Wrong cross-document expression syntax for spreadsheet aliases.
- `AssemblyLink::synchronizeJoints` copies Distance float values into the parent but
  does **not** bring the child's Params `App::Link` into the parent document.

Proposed cycle-free topology (matches DOQS skeleton/params guidance and FreeCAD
master-spreadsheet DAG pattern):

- Params live in a dedicated leaf document (`x-axis_Params.FCStd`).
- Each consumer gets `LinkMake` to the Params spreadsheet.
- Machine-level Distance constraints on the x-axis assembly are owned by `x-axis`,
  not duplicated inside linked children.

## Decisions

- Do not drive child joints from parent-linked spreadsheets via AssemblyLink sync;
  use explicit Params links in each document that needs them.

## Next Steps

- [ ] Apply the Params → LinkMake → consumer pattern across x-axis sub-assemblies.
- [ ] Capture param aliases in `cad/params/` CSV when values stabilize.

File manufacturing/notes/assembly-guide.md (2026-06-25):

# Machine assembly guide

> Scaffold — expand with step-by-step assembly, torque specs, and safety notes.

## Prerequisites

- Sub-module assembly guides under `modules/*/manufacturing/notes/` (when sub-assemblies exist)
- Build lockfile if assembling a specific serial (`builds/<id>/build.toml`)

## Overview

1. Sub-assemblies per their local guides (when `modules/` is populated).
2. Spindle clamp (`cad/assemblies/spindle-clamp/`):
   - Manufactured parts: `spindle-clamp-base` (base plate with recess for spindle clearance), `spindle-clamp-jaw` (clamping jaw), `spindle-clamp-flex` (flex part).
   - Top-down layout: master sketches in `Body_master` inside the assembly file; parts bind to those sketches (see `cad/README.md`).
   - Open the assembly in FreeCAD 1.1+ Assembly workbench; insert base and jaw parts, then add clamp joints.
3. Spindle stack: see `cad/assemblies/spindle-assembly/` (spindle model in `cad/parts/spindle/`).
4. Final machine integration at this level.

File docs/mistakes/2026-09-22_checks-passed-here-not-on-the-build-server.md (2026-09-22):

# 2026-09-22 — The checks passed on my machine and failed on the build server

## What happened

All 44 FreeCAD models got a measurement file, and every check passed locally,
including a rehearsal against the exact version of the checking tools the build
server uses. The work was pushed as passing. The build server then failed all 44
models at once, each with the same message: the model changed since its
measurement was written.

Nothing had changed. The models are stored with Git LFS, and the build server
was checking out a small text stub in place of each one. The check compares a
checksum of the model file against the checksum recorded in the measurement, so
it was comparing the measurement against a stub.

## Why it went wrong

Two habits met.

The rehearsal was careful about the wrong variable. It pinned the version of the
tools, because that had already caused one failure that day. It did not pin the
**contents of the working copy**, and that was the variable that differed: a
developer's copy has the real models, a fresh checkout does not unless it is
told to fetch them.

The error message also pointed away from the cause. "The model changed since its
measurement was written" describes the common case and reads as a statement of
fact. A stub is not a changed model, but the check cannot tell the difference
from a checksum alone.

## Prevention rule

1. **A check that reads a large binary file must be proved on a fresh checkout,
   not only on a working copy.** Anything stored with Git LFS is not there by
   default. In GitHub Actions this means `lfs: true` on the checkout step.
2. **"It passes here" is not a result.** Say which environment a check passed
   in, and name what is different about the one that matters.

## Related

- `.github/workflows/validate.yml`
- [2026-09-22_repository-passes-its-own-checks.md](../log/2026-09-22_repository-passes-its-own-checks.md)

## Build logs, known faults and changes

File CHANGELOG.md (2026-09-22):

# Changelog

All notable releases of this repository are documented here.

## [Unreleased]

### Added

- Initial DOQS repository scaffold (modular layout, validators, agent rules).
- Embedded `doqs/` tooling via Git submodule (scripts, templates, schemas).
- Spindle CAD: `cad/assemblies/spindle-assembly/`, `cad/assemblies/spindle-clamp/`, and related parts under `cad/parts/`.
- ADR-002: single top-level module (`docs/decisions/2026-06-19_single-top-level-module.md`).
- Spindle clamp sub-assembly: top-down design with `spindle-clamp-base` and `spindle-clamp-jaw` parts; recess in clamp base for spindle clearance.
- Spindle clamp flex part: `cad/parts/spindle-clamp-flex/spindle-clamp-flex.FCStd`.
- `[[part]]` entries in `okh.toml` for spindle-clamp manufactured parts.
- Guide-rail adjustment FEM study: 5 mm POM layer under the rail compressed by screw preload to correct a bend in the guide (`simulation/guide-rail-adjustment/guide-rail-adjustment.FCStd`).
- A measurement file beside every FreeCAD model, so a change to the geometry can be read as text in a pull request.
- `cad/fingerprint_models.py` writes those measurement files. Run it after saving a model in FreeCAD.
- ADR: why this repository measures hand-drawn models instead of rebuilding them (`docs/decisions/2026-09-22_fingerprints-for-hand-drawn-models.md`).

### Changed

- Split-licence layout per current DOQS spec: CERN-OHL-S v2.0 (hardware), GPL-3.0 (firmware/software/simulation), CC BY-SA 4.0 (docs/media), with `LICENSES/` full texts, `TRADEMARKS.md`, and per-directory `LICENSE` stubs.
- `doqs/` submodule bumped to include the split-licence apply/validate scripts; licence scanner skips `.agents/` tooling submodule.
- CI and onboarding validation run `doqs/scripts/validate_all.py` (includes `validate_licenses`).
- Single top-level module: removed example `modules/frame` and `modules/x-axis` scaffolds; `modules/` reserved for future sub-assemblies.
- Spindle clamp assembly: master sketches moved to `Body_master` per DOQS ADR (fixes Assembly Insert / Binder cycle); see `doqs/docs/decisions/2026-06-24_freecad-master-sketches-body.md`.
- Spindle clamp geometry: reduced clamp width; removed obsolete `spindle-clamp-design.FCStd`.
- `doqs/` submodule bumped to `71d6216` (FreeCAD master-sketches Body ADR and architecture docs).
- The automatic checks, the README and the setup guide now use one command, `python doqs/doqs.py check`. It replaces the separate validation scripts, two of which had been renamed and no longer ran.
- The build server now fetches the real FreeCAD models instead of the small stubs Git LFS leaves behind. Without this, the model check compares each measurement against a stub.
- Every shell file is now stored with Unix line endings, not only the two that were named one by one. A shell script saved with Windows line endings fails to start.

### Removed

- The example machine record `builds/serial-0042/`. It described a machine that does not exist and pointed at a version tag that was never created. The blank example to copy from, `builds/example-baseline.toml`, is unchanged.
- `bom/aggregate_bom.py`. It was an old copy of a tool that lives in the `doqs/` submodule and had fallen behind it.

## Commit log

2026-05-04 Create Accelerometer BYDDR50DZC tool mount.stl
    [Accelerometer BYDDR50DZC tool mount.stl]
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2026-06-04 Bootstrap Qarve machine repo with DOQS submodule.
    Add modular layout, example modules, agent rules, and link doqs/ at
    refaqt/doqs. Update OKH metadata for Refaqt BV.
    [500mm.csv, bom.csv, default.csv]
2026-06-19 refactor(okh): single top-level module; add spindle CAD
    Remove example modules/frame and modules/x-axis scaffolds. Operate Qarve
    as one root module with modules/ reserved for future sub-assemblies. Add
    spindle assembly CAD, update manifests and documentation.
    [500mm.csv, bom.csv, default.csv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]
2026-06-19 Fixed spindle-clamp-base Binder link error
    [spindle-clamp-base.FCStd]
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2026-06-23 Recess in spindle clamp
    [spindle-clamp-base.FCStd, spindle-clamp.FCStd]
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2026-06-24 cad: commit spindle clamp design FreeCAD files
    Include clamp base/jaw parts, assembly, design workspace, and spindle updates from the latest design iteration.
    [spindle-assembly.FCStd, spindle-clamp-base.FCStd, spindle-clamp-design.FCStd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]
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2026-06-24 cad: update spindle assembly and clamp geometry, add spacer part
    [spindle-assembly.FCStd, spindle-clamp-base.FCStd, spindle-clamp-design.FCStd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]
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2026-06-25 cad: reduce spindle clamp width
    Update spindle clamp assembly and parts; remove obsolete spindle-clamp-design.
    [spindle-clamp-base.FCStd, spindle-clamp-design.FCStd, spindle-clamp-jaw.FCStd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]
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2026-06-25 cad: add spindle clamp flex and update docs
    Add spindle-clamp-flex part and include spindle reference model; update OKH sources/parts and related docs.
    [spindle-clamp-flex.FCStd, spindle.FCStd]
2026-06-25 docs(prompts-log): record spindle and flex commit
    Log CAD+docs update for spindle and spindle-clamp-flex.
2026-06-25 cad: update spindle clamp geometry and log
    Record the spindle clamp width reduction trade-offs and update related spindle CAD models.
    [spindle-assembly.FCStd, spindle-clamp-base.FCStd, spindle-clamp-jaw.FCStd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]
2026-06-25 cad: add z-slide assembly, guide rail simulation, spindle work
    - Add z-axis assembly and guide block, guide rail, and linear motor forcer/magnet parts (FreeCAD + STEP sources)
    - Add guide-rail-adjustment FEM simulation with compliant support layer
    - Bump doqs submodule pointer
    - Ignore regenerable FreeCAD extract artifacts (fcstd-extract/, *.zip)
    [HGL15CAZBC_E2_FILE_2.stp, HGR15R480C_FILE_1.stp, guide-block.FCStd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]
2026-06-26 docs: log guide-rail adjustment simulation
    Simulated correcting a bend in the linear guide via a 5 mm POM layer under
    the rail compressed by the screw preload. Results in
    simulation/guide-rail-adjustment/guide-rail-adjustment.FCStd.
    Ignore regenerable CalculiX solver artifacts (FEMMeshGmsh.*).
    [guide-rail-adjustment.FCStd]
2026-06-29 Set up subassemblies with flexible joints
    [guide-rail-adjustment.FCStd, guide-rail-support-z.FCStd, linear-guide-z.FCStd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]
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2026-07-13 Fixed assembly error
    [z-axis.FCStd]
2026-07-14 Update z-axis and machine CAD, add FreeCAD agent skill, bump doqs.
    Advance z-axis assembly work with pneumatic cylinder and machine top-level assembly; wire FreeCAD debugging skill into Cursor rules and update doqs submodule.
    [linear-encoder-2.FCStd, linear-motor-z.FCStd, machine.FCStd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]
2026-07-14 Updated z-axis design
    Removed rail support because z-axis-base can be precision milled to achieve good straightness.
    [linear-encoder-rail-spacer.FCStd, z-axis.FCStd]
2026-07-15 Created simplified part model of spindle, x and z-axis for FEM analysis
    [machine-fem.FCStd, z-axis.FCStd]
2026-07-15 Updated FEM simulation
    Selected the right solids, reapplied materials, reapplied constraints
    [machine-fem.FCStd]
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2026-07-16 Updated design overview and fixed FEM simulation
    - Design overview updated with latest BOM
    - FEM simulation fixed by not assigning solids to Aluminium (remaining Solids are automatically assigned to Aluminium)
    [machine-fem.FCStd]
2026-07-16 Eigenfrequency analysis. Recovered Designs from crash.
    [guide-block.FCStd, guide-rail-z.FCStd, linear-encoder-2.FCStd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]
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2026-07-17 Added frontplate to spindle and backplate to gantry
    [machine-fem.FCStd]
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2026-07-17 Adjusted side walls of axes for cable carriers
    [machine-fem.FCStd]
2026-07-17 FEM model up to Y axis guide rail
    [machine-fem.FCStd]
2026-07-20 Y-axis configuration of linear motor, guide and encoder
    [machine-fem.FCStd, spindle-assembly.FCStd, spindle-clamp-base.FCStd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]
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2026-07-22 Design new configuration of linear axis
    More compact design with exposed linear encoder, bellows and 190 mm width.
    [linear-axis-configuration.FCStd]
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2026-08-17 Update linear axis architecture - steel strip sealing
    [machine.FCStd]
2026-08-18 Removed bellows design
    Removed bellows design and moved it to Google Drive
    [bellows-flat-test-rib.stl, bellows-flat-test-sheet.stl, bellows-flat-test.FCStd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]
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2026-09-22 cad(linear-axis): make room for larger steel strip seal rollers
    The axis profile is 15 mm wider and the rail carriages sit 5 mm closer
    together. This gives 14 mm of free space next to each carriage instead
    of 4 mm, so a larger seal roller fits.
    [machine.FCStd]
2026-09-22 cad(linear-axis): close the top and redraw the strip seal path
    The steel strip seal now runs over a closed top instead of a side
    pocket. The side walls moved inward and the seal rollers are smaller:
    10 mm and 9.8 mm across, instead of 14 mm and 13.8 mm.
    [machine.FCStd]
2026-09-22 chore: drop the old copy of the parts-list tool
    bom/aggregate_bom.py was a copy of a tool that lives in the doqs
    submodule. The shared one has since learned to handle product families
    and the new parts-list columns; the copy had not, and would have written
    a wrong list without saying so.
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2026-09-22 cad: measure all 44 models, and save the linear axis change
    The model and its measurement have to arrive together, or the checks
    fail on the commit in between. cad/architecture/machine.FCStd carries
    the linear axis work from the FreeCAD session on 22 September.
    Three models move when FreeCAD refreshes them, so they no longer agree
    with their own sketches and joints. The measurements record what the
    saved files hold, which is correct. The activity log names the three.
    [linear-motor-forcer.fingerprint.json, linear-motor-magnet-1.fingerprint.json, linear-motor-magnet-2.fingerprint.json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]
2026-09-22 chore: keep every shell file on Unix line endings
    Only setup-tooling.sh and syson.sh were named, so the session start-up
    script was not covered. A shell script saved with Windows line endings
    fails to start. This also brings that script up to the current shared
    template, which finds the repository from its own location.
2026-09-23 feat(cad): redraw the linear stage base as one aluminium block
    The base is 3.5 mm lower, gets T-slots on top, and the seal rollers
    move out and down to follow it. The log entry keeps the hand sketch.
    [machine.FCStd, machine.fingerprint.json]
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2026-09-25 feat(cad): thicker strip seal on a larger bend radius
    The strip seal is now 0.25 mm thick instead of 0.1 mm. It follows
    S-curves with a bend radius of about 32 mm instead of wrapping each
    roller at about 5 mm. This cuts the bending stress to less than half.
    [machine.FCStd, machine.fingerprint.json]
2026-09-28 docs(log): compare grblHAL and ncSender with LinuxCNC and EtherCAT
    Also adds the missing 2026-09-25 strip seal entry to the log index.
    Claude-Session: https://claude.ai/code/session_01Q3XaaxuwvNemk4k3QTJyWR
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2026-11-12 Move the layout models to cad/assemblies/architecture
    The newer doqs requires every Body in a part document to sit inside a
    Part container, and exempts only cad/assemblies/. The six layout models
    in cad/architecture/ are top-down documents (sketches, datums, binders),
    not parts, so CI failed on all of them.
    Move the folder as a whole and keep the file names: the fingerprints
    record only the file name and checksum, so they stay valid, and no
    .FCStd file is edited. Update the log paths and record the decision.
    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
